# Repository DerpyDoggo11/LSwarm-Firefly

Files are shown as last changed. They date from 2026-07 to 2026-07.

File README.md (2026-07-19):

# LSwarm Firefly
A single motor Micro-Aerial Vehicle for drone swarm light displays

## Case
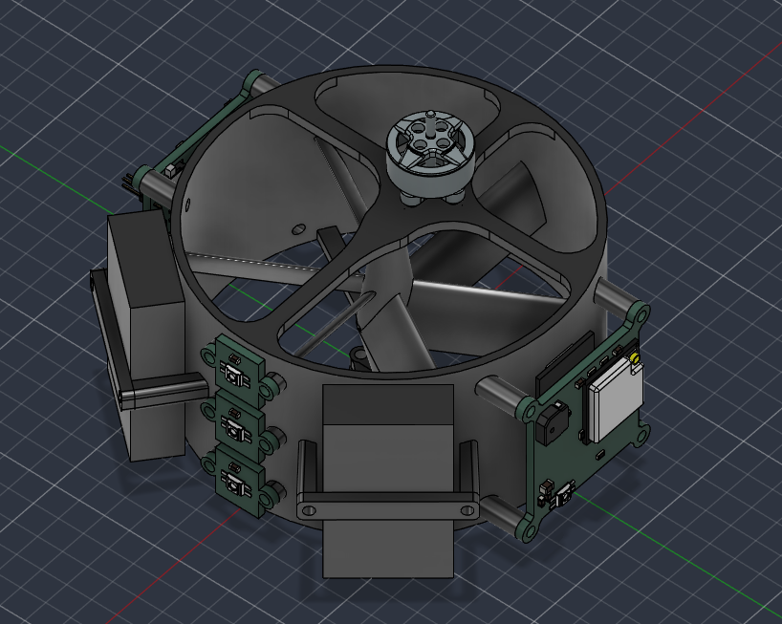
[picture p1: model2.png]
Case


## 3D PCB Preview
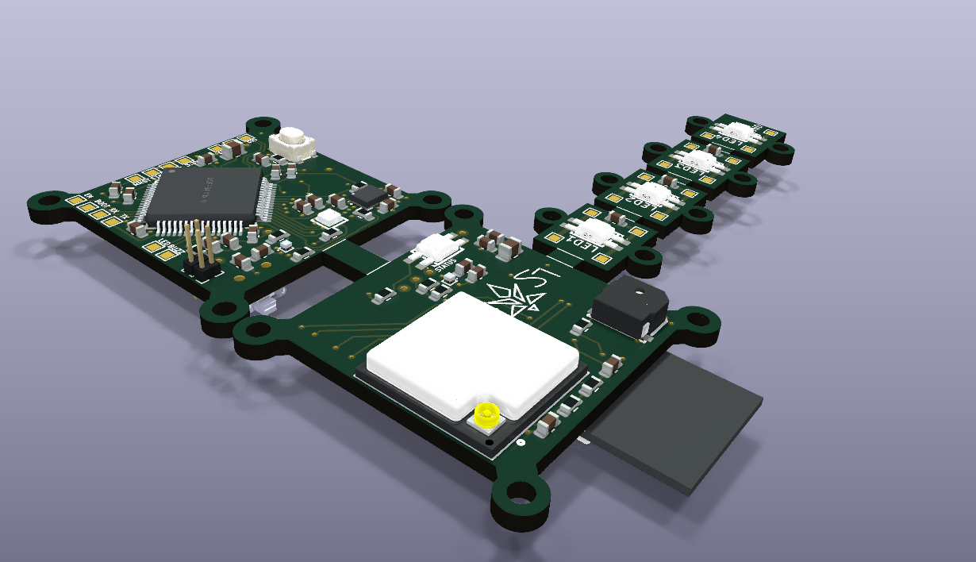
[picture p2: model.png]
3D PCB


## PCB Wiring
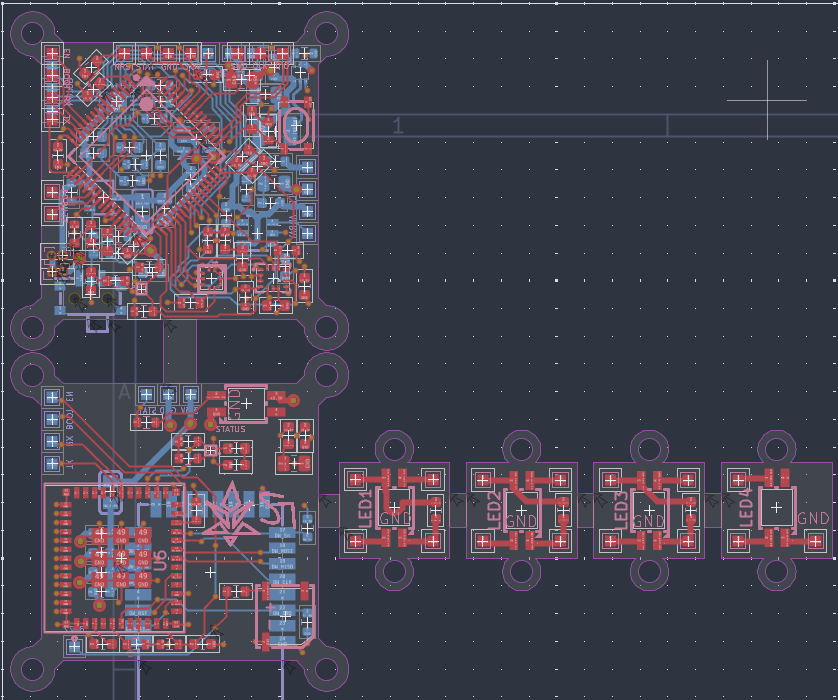
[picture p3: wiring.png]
PCB


## PCB Schematic
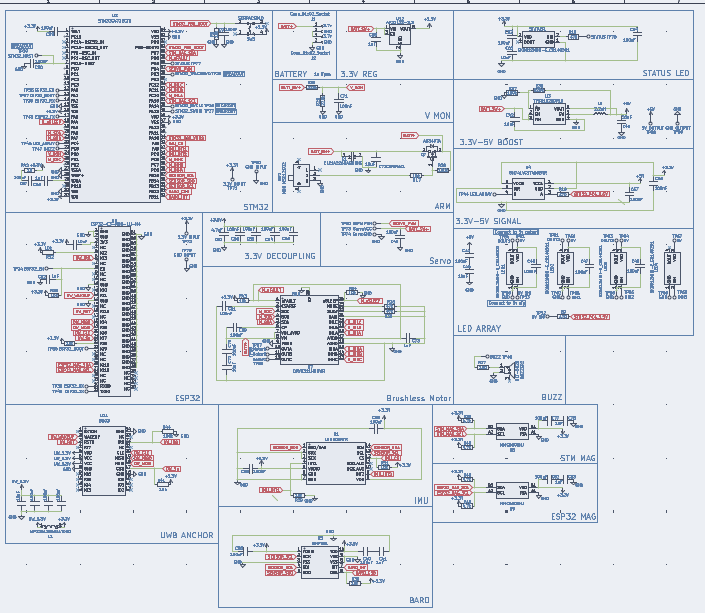
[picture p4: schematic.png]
Schematic


### Download ./latestProduction to fabricate your own PCB.

## Introduction
The LS Firefly is the baby brother to the original [LS Mk.1](https://github.com/DerpyDoggo11/LSwarm), the goal is to be smaller, safer, and a little more unique than the previous drone. Although it does come at some costs such as reduced manuverability and no USB-C connectivity. Like the previous model, rather than using GPS, it uses UWB frequencies to communicate with ground anchors (see [LS Anchor](https://github.com/DerpyDoggo11/LSwarm-Anchor)) for positioning. To fabricate these drones yourself, see the bill of materials below and follow the instructions. 

Note: this drone is all open sourced under the GNU GPL license! (do what you will with the code and designs but make sure to keep it open-source! :D)

### Are drone swarms legal in the US?
TLDR: yes and no, mostly no but sometimes yes. 

In the US, flying more than one drone by yourself outside is technically not legal without a permit, but flying indoors (or under some netting outside) is perfectly allowed, so make sure you understand this before buying or assembling any components.

If you live outside of the US, the restrictions will be different so make sure you check with your local government. 

## Bill of Materials 

### (Minimum build for testing: 5 drones)

| Quantity | Components | Price | Link |
|--- |---|---| -----|
| 5  | Brushless Motors | ~$56.27  | [here](https://www.aliexpress.us/item/3256811751884831.html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)
| 5 | 65mm Propellers (1.5mm hole) | $2.42 | [here](https://www.aliexpress.us/item/3256808528649872.html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) 
| 10  | 1s 300mAh Battery | ~$19.75 | [here](https://www.aliexpress.us/item/3256801127609470.html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) 
|5 | 2.4G Wifi Antennas | ~$3.52 | [here](https://www.aliexpress.us/item/3256802833801038.html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)
| 5  | LS Firefly PCBs | ~$25 (with shipping, cost can vary widely however) | Download repo, extract fabrication files, and fabricate pcb through JLCPCB, purchase components from LCSC (complete instructions for this may come soon)
| 5  | Electronics | ~$125 (with shipping, cost can vary widely however) | Purchase components from LCSC

Total cost: **$231,96**

Cost per drone: **$46.39**

## Tools / Other parts:
- Hot-air reflow station or SMD hot plate
- Soldering iron + solder
- Solder paste for SMD components
- Tweezers for SMD components

For drone light displays, you'll also need the [UWB anchors](https://github.com/DerpyDoggo11/LSwarm-Anchor) and a powerful MCU devboard or laptop.

## Assembly:
1. Apply solder paste to all smd components directly or through a stencil
2. Heat up components with a hot plate or hot-air gun
3. 3D print drone case
4. Mount components to drone case
4. Plug in USB-C port and upload software

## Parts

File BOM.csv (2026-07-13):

Quantity | Component | Price | Link
5 | Brushless Motor | $56.27 | https://www.aliexpress.us/item/3256811751884831.html?curPageLogUid=VGuc6eNMjhlE
5 | 1s 300mAh Battery | $19.75 | https://www.aliexpress.us/item/3256801127609470.html?curPageLogUid=hyAg3GWOKWbh
5 | 65mm Propellers (1.5mm hole) | $2.42 | https://www.aliexpress.us/item/3256808528649872.html?curPageLogUid=khfzd3PNDSbd
5 | 2.4G Wifi Antenna | $3.52 | https://www.aliexpress.us/item/3256802833801038.html?curPageLogUid=rLnZuf4b98Bi
5 | Custom PCB | $25 | Download repo, extract fabrication files, and fabricate pcb through JLCPCB
5 | Electronics | $125 | Purchase components from LCSC
Total: | $231.96
Cost Per Drone | $46.39

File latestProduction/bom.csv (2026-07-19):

Designator | Footprint | Quantity | Value | LCSC Part #
BUZZER2 | BUZ-SMD_L5.0-W5.5-P4.60 | 1 | MLT-5020 | C94598
C1 | C0805 | 1 | CL21A226MAQNNNE | C45783
C38, C39, C40, C44, C46, C47, C48, C50, C53, C54, C56, C57, C59, C60, C61, C62, C64, C66, C67, C68, C69, C70, C71, C77, C79, C80, C81, C82, C9 | 0603 | 29 | 100nF
C41, C52, C58, C65, C73, C78, C83 | 0603 | 7 | 1uF
C42, C45, C63, C71CERAMIC1 | 0805 | 4 | 10uF
C43 | 0805 | 1 | 22uF
C49 | 0603 | 1 | 100uF
C51 | 0603 | 1 | 4.7uF
C55, C72, C76 | 0603 | 3 | 10uF
J1, J2 | PinHeader_1x02_P1.00mm_Vertical | 2 | Conn_01x02_Socket
L1 | L0805 | 1 | MPZ2012S601AT000 | C21519
L5 | 1210 | 1 | 2.2uH
LED1, LED2, LED3, LED4, STATUS1 | LED-SMD_4P-L3.2-W2.8-LS5.9_SK6812MINI-E | 5 | SK6812MINI-E_C5149201 | C5149201
Q7 | SOT-23-3_L2.9-W1.6-P1.90-LS2.8-BR | 1 | AO3407A | C15155
R10, R19, R9 | 0603 | 3 | 470
R17, R18, R29, R30, R31, R32, R33, R34, R41, R43, R8 | 0603 | 11 | 10k
R25, R26 | 0603 | 2 | 220k
R27 | 0603 | 1 | 100
R28, R37, R44 | 0603 | 3 | 100k
R35, R39 | 0603 | 2 | 47k
R36 | 0603 | 1 | 820k
R38, R40, R45, R46 | 0603 | 4 | 4.7k
R42 | 0603 | 1 | 10
SW2 | SW-SMD_MSK12CO2 | 1 | MINI MSK12CO2 | C2681570
SW3 | KEY-SMD_4P-L4.2-W3.2-P2.20-LS4.6 | 1 | SKRPACE010 | C139797
TP26 | TestPoint_Pad_1.0x1.0mm | 1 | STM32_SWCLK
TP27 | TestPoint_Pad_1.0x1.0mm | 1 | STM32_SWDIO
TP28 | TestPoint_Pad_1.0x1.0mm | 1 | STM32_TRACESWO
TP29 | TestPoint_Pad_1.0x1.0mm | 1 | STM32_NRST
TP34, TP35 | TestPoint_Pad_1.0x1.0mm | 2 | ESP32_EN
TP36, TP37 | TestPoint_Pad_1.0x1.0mm | 2 | ESP32_BOOT
TP38, TP39 | TestPoint_Pad_1.0x1.0mm | 2 | ESP32_RX
TP40, TP43 | TestPoint_Pad_1.0x1.0mm | 2 | ESP32_TX
TP44, TP45 | TestPoint_Pad_1.0x1.0mm | 2 | LED_ARRAY
TP46, TP47 | TestPoint_Pad_1.0x1.0mm | 2 | BUZZ
TP50 | TestPoint_Pad_1.0x1.0mm | 1 | ServoPWM
TP51, TP60, TP64, TP67 | TestPoint_Pad_1.0x1.0mm | 4 | 5V
TP52, TP53 | TestPoint_Pad_1.0x1.0mm | 2 | 5V SIG
TP54 | TestPoint_Pad_1.0x1.0mm | 1 | DOUT1
TP55 | TestPoint_Pad_1.0x1.0mm | 1 | DIN1
TP56, TP62, TP66, TP69 | TestPoint_Pad_1.0x1.0mm | 4 | GND
TP58 | TestPoint_Pad_1.0x1.0mm | 1 | 5V OUTPUT
TP59 | TestPoint_Pad_1.0x1.0mm | 1 | GND OUTPUT
TP61 | TestPoint_Pad_1.0x1.0mm | 1 | DOUT2
TP63 | TestPoint_Pad_1.0x1.0mm | 1 | DOUT3
TP65 | TestPoint_Pad_1.0x1.0mm | 1 | DIN2
TP68 | TestPoint_Pad_1.0x1.0mm | 1 | DIN3
TP71, TP72 | TestPoint_Pad_1.0x1.0mm | 2 | 3.3V INPUT
TP73 | TestPoint_Pad_1.0x1.0mm | 1 | ServoVCC
TP74 | TestPoint_Pad_1.0x1.0mm | 1 | ServoGND
TP76, TP77 | TestPoint_Pad_1.0x1.0mm | 2 | STATUS
TP79, TP80 | TestPoint_Pad_1.0x1.0mm | 2 | GND INPUT
TP87 | TestPoint_Pad_1.0x1.0mm | 1 | MotorA
TP88 | TestPoint_Pad_1.0x1.0mm | 1 | MotorB
TP89 | TestPoint_Pad_1.0x1.0mm | 1 | MotorC
U1 | LGA-14_L3.0-W2.5-P0.50-BR | 1 | LSM6DSRTR | C784817
U11 | WIRELM-SMD_BU03 | 1 | BU03 | C42419011
U12 | SOT-23-5 | 1 | AP2112K-3.3
U2 | LQFP-64_L10.0-W10.0-P0.50-LS12.0-BL | 1 | STM32G473RCT6 | C529361
U3 | SOT-563_L1.6-W1.2-P0.50-LS1.6-BR | 1 | TPS61023DRLR | C919459
U4 | SOT-23-6_L2.9-W1.6-P0.95-LS2.8-BR | 1 | SN74LVC1T45DBVR | C7843
U5 | LGA-10_L2.0-W2.0-P0.50-TL_BMP581 | 1 | BMP581 | C5362283
U6 | WIFIM-SMD_61P-L13.2-W12.5-P0.80 | 1 | ESP32-C3-MINI-1U-N4 | C2911374
U7 | QFN-24_L3.0-W3.0-P0.40-TL-EP1.9_TI_RRW0024A | 1 | DRV8311HRRWR | C5218862
U8, U9 | FLIPCHIP-4_L0.8-W0.8-R2-C2-P0.40-TL | 2 | MMC5603NJ | C404328

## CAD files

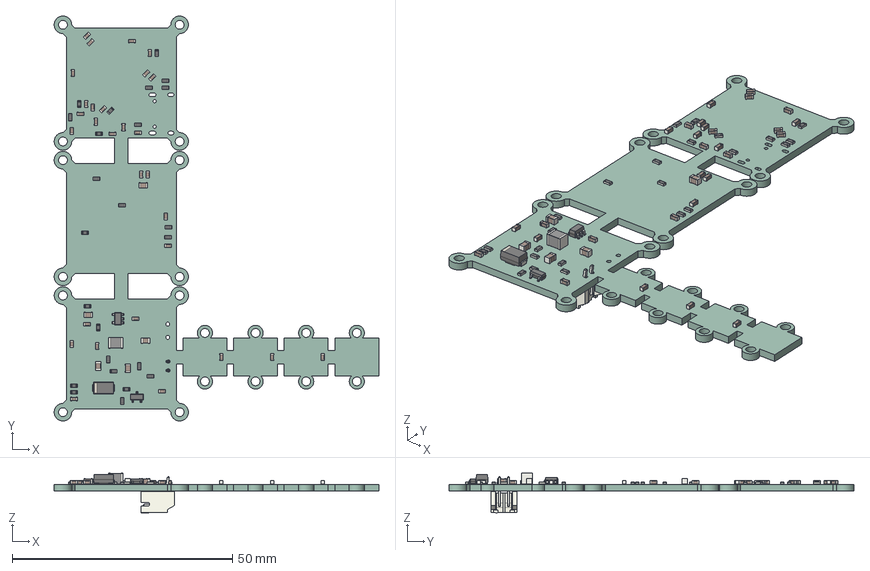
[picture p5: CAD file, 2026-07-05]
LSwarm Firefly/LSwarm Firefly.step
73.7 x 92.0 x 9.03 mm
SOT-23-5
C_0603_1608Metric x 29
R_0603_1608Metric x 24
D_SMA
C_0805_2012Metric x 5
L_1210_3225Metric
SOT-23
JST_PH_S2B-PH-K_1x02_P2.00mm_Horizontal
LSwarm Firefly_PCB

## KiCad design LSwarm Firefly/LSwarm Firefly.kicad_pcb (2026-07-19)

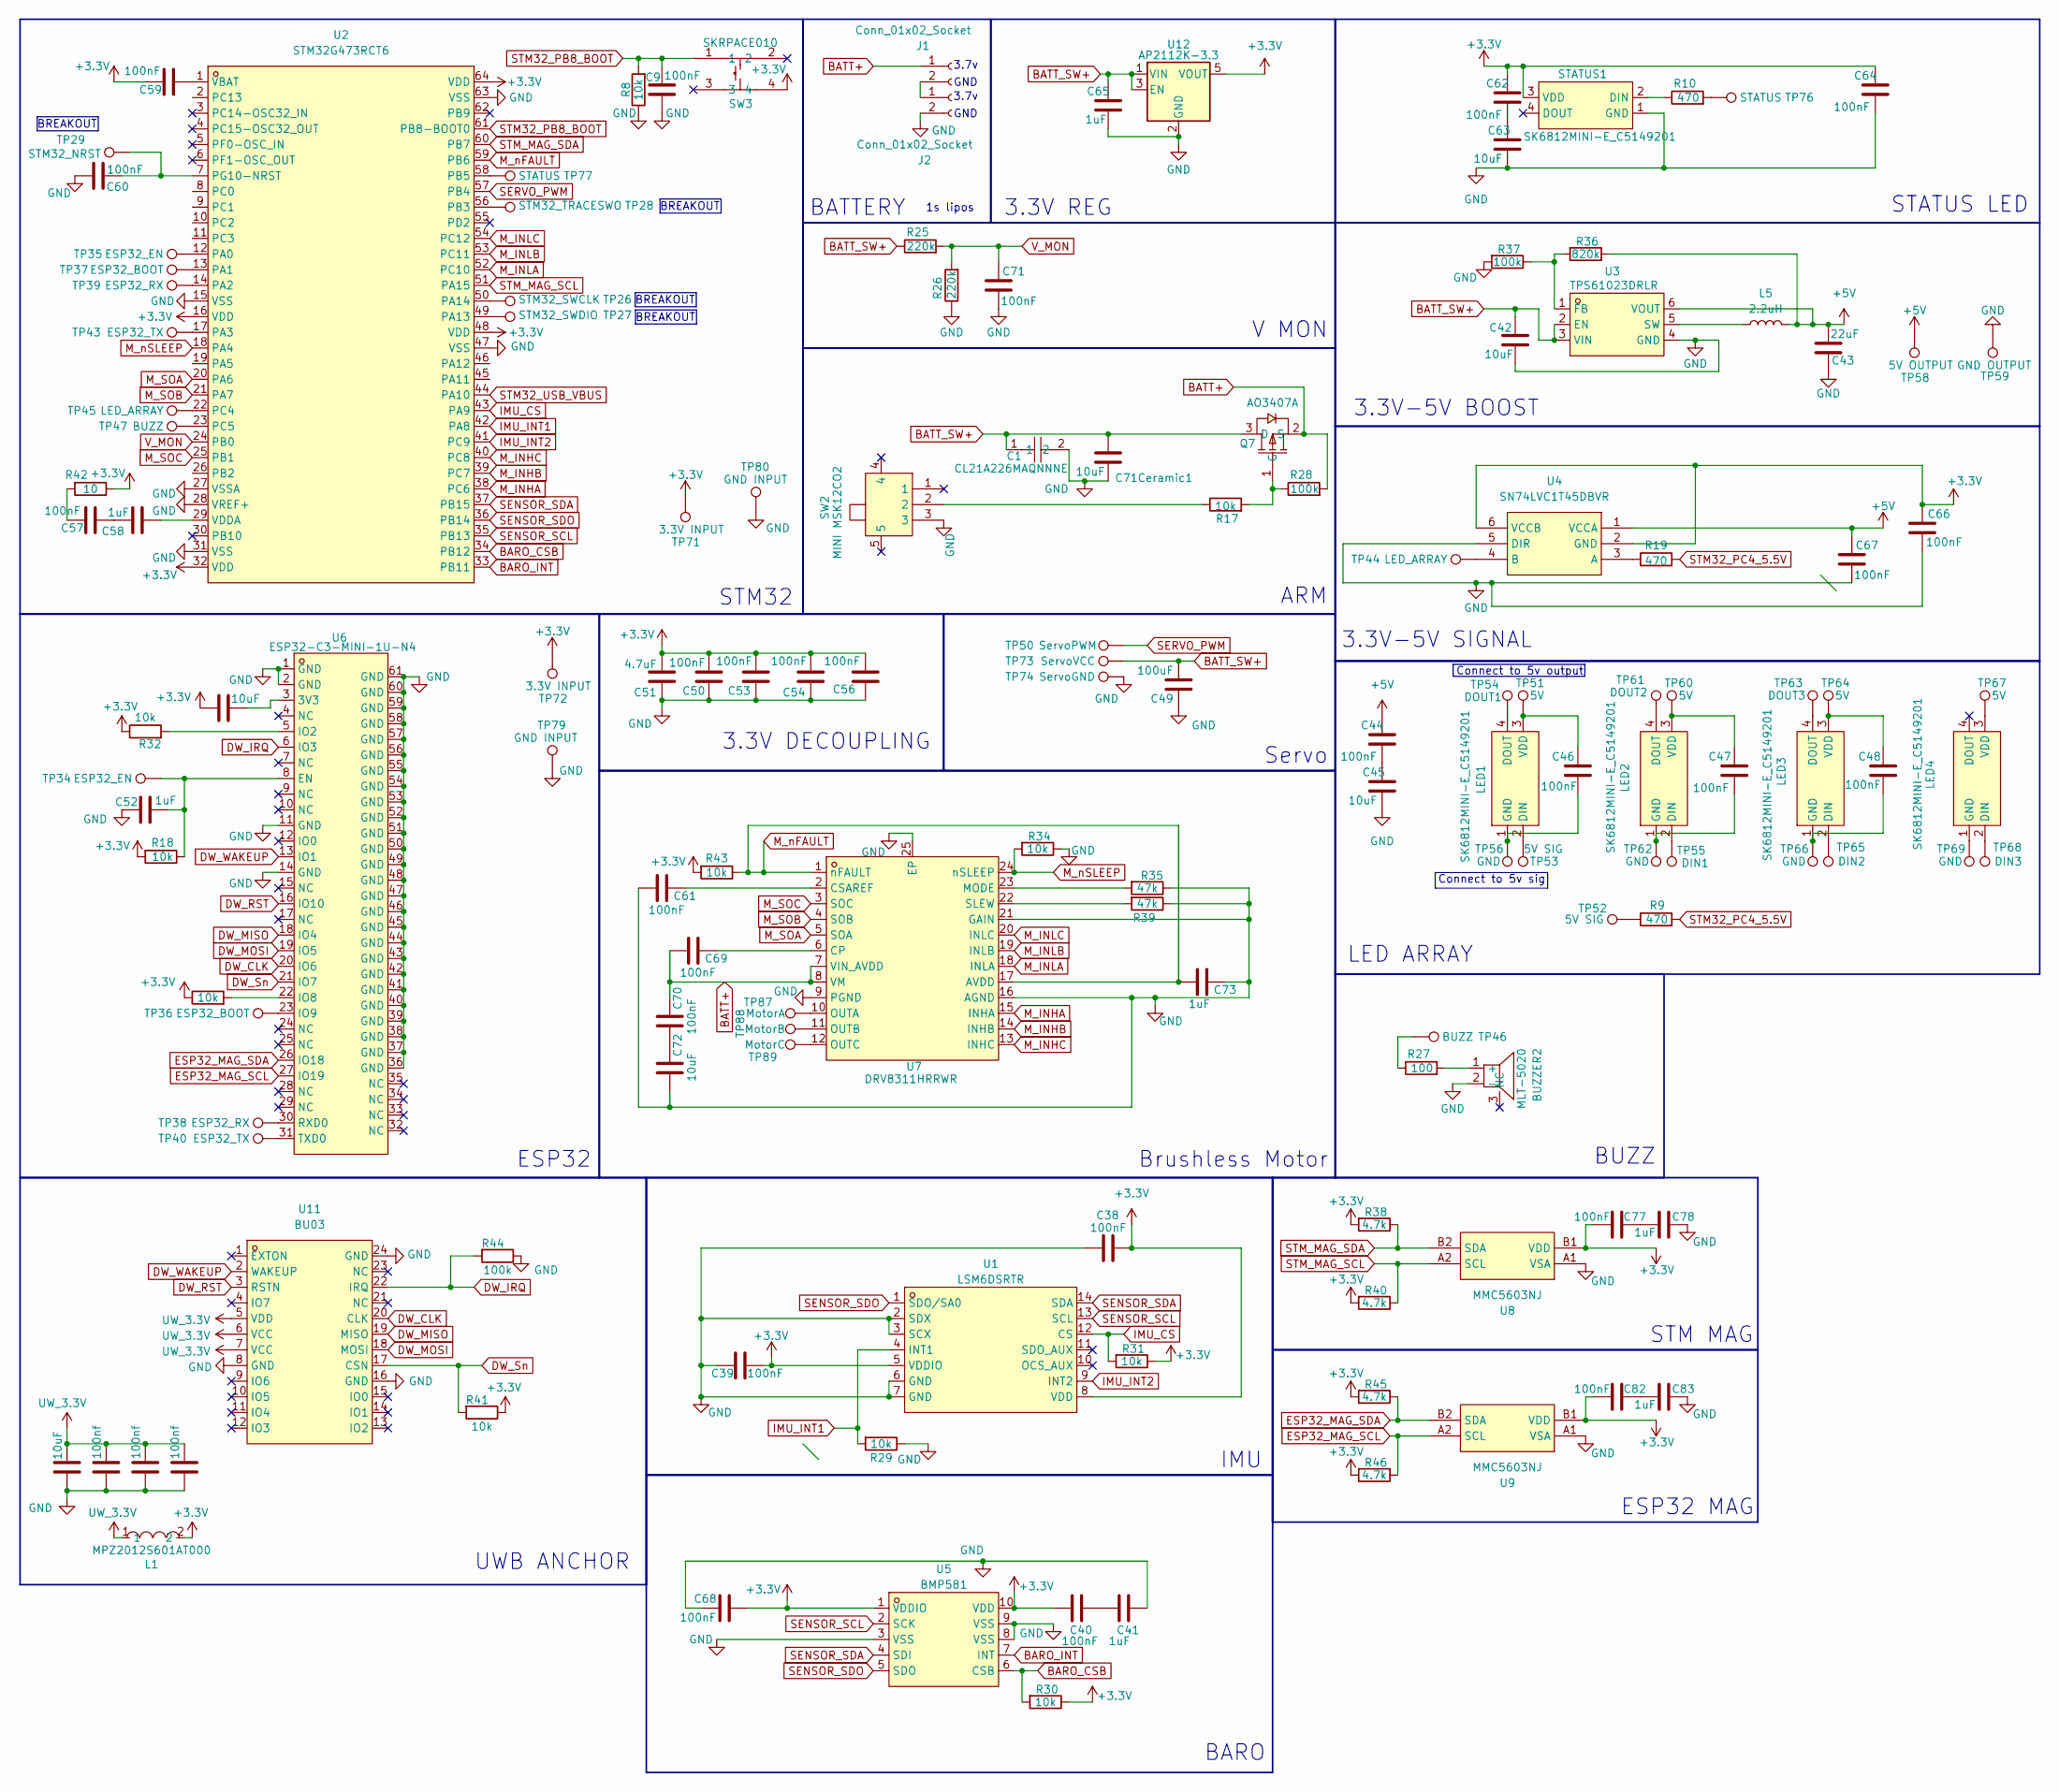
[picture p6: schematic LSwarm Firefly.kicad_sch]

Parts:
BUZZER2: MLT-5020; BUZ-SMD_L5.0-W5.5-P4.60; MPN MLT-5020; LCSC Part C94598
C1: CL21A226MAQNNNE; C0805; MPN CL21A226MAQNNNE; LCSC Part C45783
C9, C38, C39, C40, C44, C46, C47, C48, C50, C53, C54, C56, C57, C59, C60, C61, C62, C64, C66, C67, C68, C69, C70, C71, C77, C82: 100nF; C_0603_1608Metric
C41, C52, C58, C65, C73, C78, C83: 1uF; C_0603_1608Metric
C42, C45, C63, C71Ceramic1: 10uF; C_0805_2012Metric
C43: 22uF; C_0805_2012Metric
C49: 100uF; C_0603_1608Metric
C51: 4.7uF; C_0603_1608Metric
C55, C72, C76: 10uF; C_0603_1608Metric
C79, C80, C81: 100nf; C_0603_1608Metric
J1, J2: Conn_01x02_Socket; PinHeader_1x02_P1.00mm_Vertical
L1: MPZ2012S601AT000; L0805; MPN MPZ2012S601AT000; LCSC Part C21519
L5: 2.2uH; L_1210_3225Metric
LED1, LED2, LED3, LED4: SK6812MINI-E_C5149201; LED-SMD_4P-L3.2-W2.8-LS5.9_SK6812MINI-E; MPN SK6812MINI-E; LCSC Part C5149201
Q7: AO3407A; SOT-23-3_L2.9-W1.6-P1.90-LS2.8-BR; MPN AO3407A; LCSC Part C15155
R8, R17, R18, R29, R30, R31, R32, R33, R34, R41, R43: 10k; R_0603_1608Metric
R9, R10, R19: 470; R_0603_1608Metric
R25, R26: 220k; R_0603_1608Metric
R27: 100; R_0603_1608Metric
R28, R37, R44: 100k; R_0603_1608Metric
R35, R39: 47k; R_0603_1608Metric
R36: 820k; R_0603_1608Metric
R38, R40, R45, R46: 4.7k; R_0603_1608Metric
R42: 10; R_0603_1608Metric
STATUS1: SK6812MINI-E_C5149201; LED-SMD_4P-L3.2-W2.8-LS5.9_SK6812MINI-E; MPN SK6812MINI-E; LCSC Part C5149201
SW2: MINI MSK12CO2; SW-SMD_MSK12CO2; MPN MINI MSK12CO2; LCSC Part C2681570
SW3: SKRPACE010; KEY-SMD_4P-L4.2-W3.2-P2.20-LS4.6; MPN SKRPACE010; LCSC Part C139797
TP26: STM32_SWCLK; TestPoint_Pad_1.0x1.0mm
TP27: STM32_SWDIO; TestPoint_Pad_1.0x1.0mm
TP28: STM32_TRACESWO; TestPoint_Pad_1.0x1.0mm
TP29: STM32_NRST; TestPoint_Pad_1.0x1.0mm
TP34, TP35: ESP32_EN; TestPoint_Pad_1.0x1.0mm
TP36, TP37: ESP32_BOOT; TestPoint_Pad_1.0x1.0mm
TP38, TP39: ESP32_RX; TestPoint_Pad_1.0x1.0mm
TP40, TP43: ESP32_TX; TestPoint_Pad_1.0x1.0mm
TP44, TP45: LED_ARRAY; TestPoint_Pad_1.0x1.0mm
TP46, TP47: BUZZ; TestPoint_Pad_1.0x1.0mm
TP50: ServoPWM; TestPoint_Pad_1.0x1.0mm
TP51, TP60, TP64, TP67: 5V; TestPoint_Pad_1.0x1.0mm
TP52, TP53: 5V SIG; TestPoint_Pad_1.0x1.0mm
TP54: DOUT1; TestPoint_Pad_1.0x1.0mm
TP55: DIN1; TestPoint_Pad_1.0x1.0mm
TP56, TP62, TP66, TP69: GND; TestPoint_Pad_1.0x1.0mm
TP58: 5V OUTPUT; TestPoint_Pad_1.0x1.0mm
TP59: GND OUTPUT; TestPoint_Pad_1.0x1.0mm
TP61: DOUT2; TestPoint_Pad_1.0x1.0mm
TP63: DOUT3; TestPoint_Pad_1.0x1.0mm
TP65: DIN2; TestPoint_Pad_1.0x1.0mm
TP68: DIN3; TestPoint_Pad_1.0x1.0mm
TP71, TP72: 3.3V INPUT; TestPoint_Pad_1.0x1.0mm
TP73: ServoVCC; TestPoint_Pad_1.0x1.0mm
TP74: ServoGND; TestPoint_Pad_1.0x1.0mm
TP76, TP77: STATUS; TestPoint_Pad_1.0x1.0mm
TP79, TP80: GND INPUT; TestPoint_Pad_1.0x1.0mm
TP87: MotorA; TestPoint_Pad_1.0x1.0mm
TP88: MotorB; TestPoint_Pad_1.0x1.0mm
TP89: MotorC; TestPoint_Pad_1.0x1.0mm
U1: LSM6DSRTR; LGA-14_L3.0-W2.5-P0.50-BR; MPN LSM6DSRTR; LCSC Part C784817
U2: STM32G473RCT6; LQFP-64_L10.0-W10.0-P0.50-LS12.0-BL; MPN STM32G473RCT6; LCSC Part C529361
U3: TPS61023DRLR; SOT-563_L1.6-W1.2-P0.50-LS1.6-BR; MPN TPS61023DRLR; LCSC Part C919459
U4: SN74LVC1T45DBVR; SOT-23-6_L2.9-W1.6-P0.95-LS2.8-BR; MPN SN74LVC1T45DBVR; LCSC Part C7843
U5: BMP581; LGA-10_L2.0-W2.0-P0.50-TL_BMP581; MPN BMP581; LCSC Part C5362283
U6: ESP32-C3-MINI-1U-N4; WIFIM-SMD_61P-L13.2-W12.5-P0.80; MPN ESP32-C3-MINI-1U-N4; LCSC Part C2911374
U7: DRV8311HRRWR; QFN-24_L3.0-W3.0-P0.40-TL-EP1.9_TI_RRW0024A; MPN DRV8311HRRWR; LCSC Part C5218862
U8, U9: MMC5603NJ; FLIPCHIP-4_L0.8-W0.8-R2-C2-P0.40-TL; MPN MMC5603NJ; LCSC Part C404328
U11: BU03; WIRELM-SMD_BU03; MPN BU03; LCSC Part C42419011
U12: AP2112K-3.3; SOT-23-5

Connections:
+3.3V: C38.1, C39.1, C40.2, C50.2, C51.2, C53.2, C54.2, C55.2, C56.2, C59.1, C62.2, C64.2, C66.2, C68.1, C77.1, C82.1, L1.2, R18.2, R30.1, R31.1, R32.1, R33.1, R38.2, R40.2, R41.1, R42.1, R43.2, R45.2, R46.2, STATUS1.3 (VDD), SW3.4, TP71.1 (1_1), TP72.1 (1_1), U1.5 (VDDIO), U1.8 (VDD), U2.16 (VDD), U2.32 (VDD), U2.48 (VDD), U2.64 (VDD), U4.2 (GND), U4.6 (VCCB), U5.1 (VDDIO), U5.10 (VDD), U8.B1 (VDD), U9.B1 (VDD), U12.5 (VOUT)
+5V: C43.2, C44.2, C67.2, L5.2, R36.1, TP58.1 (1_1), U3.6 (VOUT), U4.1 (VCCA)
BARO_CSB: R30.2, U2.34 (PB12), U5.6 (CSB)
BARO_INT: U2.33 (PB11), U5.7 (INT)
BATT+: C69.2, C70.1, J1.1, Q7.2 (S), R28.2, U7.7 (VIN_AVDD), U7.8 (VM)
BATT_SW+: C1.1, C42.1, C49.2, C65.2, C71Ceramic1.2, Q7.3 (D), R25.1, TP73.1 (1_1), U3.2 (EN), U3.3 (VIN), U12.1 (VIN), U12.3 (EN)
DW_CLK: U6.20 (IO6), U11.20 (CLK)
DW_IRQ: R44.2, U6.6 (IO3), U11.22 (IRQ)
DW_MISO: U6.18 (IO4), U11.19 (MISO)
DW_MOSI: U6.19 (IO5), U11.18 (MOSI)
DW_RST: U6.16 (IO10), U11.3 (RSTN)
DW_Sn: R41.2, U6.21 (IO7), U11.17 (CSN)
DW_WAKEUP: U6.13 (IO1), U11.2 (WAKEUP)
ESP32_MAG_SCL: R46.1, U6.27 (IO19), U9.A2 (SCL)
ESP32_MAG_SDA: R45.1, U6.26 (IO18), U9.B2 (SDA)
GND: BUZZER2.2 (-), C1.2, C9.2, C38.2, C39.2, C41.1, C42.2, C43.1, C45.1, C49.1, C50.1, C51.1, C52.1, C53.1, C54.1, C56.1, C60.1, C61.2, C63.1, C64.1, C65.1, C66.1, C67.1, C68.2, C71.1, C71Ceramic1.1, C72.2, C73.1, C76.2, C78.2, C79.2, C80.2, C81.2, C83.2, J2.2, R8.1, R26.1, R29.1, R34.1, R35.1, R37.2, R39.1, R44.1, STATUS1.1 (GND), SW2.3, TP59.1 (1_1), TP74.1 (1_1), TP79.1 (1_1), TP80.1 (1_1), U1.2 (SDX), U1.3 (SCX), U1.6 (GND), U1.7 (GND), U2.15 (VSS), U2.27 (VSSA), U2.28 (VREF+), U2.31 (VSS), U2.47 (VSS), U2.63 (VSS), U3.4 (GND), U4.5 (DIR), U5.3 (VSS), U5.8 (VSS), U5.9 (VSS), U6.1 (GND), U6.2 (GND), U6.11 (GND), U6.14 (GND), U6.36 (GND), U6.37 (GND), U6.38 (GND), U6.39 (GND), U6.40 (GND), U6.41 (GND), U6.42 (GND), U6.43 (GND), U6.44 (GND), U6.45 (GND), U6.46 (GND), U6.47 (GND), U6.48 (GND), U6.49 (GND), U6.50 (GND), U6.51 (GND), U6.52 (GND), U6.53 (GND), U6.54 (GND), U6.55 (GND), U6.56 (GND), U6.57 (GND), U6.58 (GND), U6.59 (GND), U6.60 (GND), U6.61 (GND), U7.9 (PGND), U7.16 (AGND), U7.21 (GAIN), U7.25 (EP), U8.A1 (VSA), U9.A1 (VSA), U11.8 (GND), U11.16 (GND), U11.24 (GND), U12.2 (GND)
IMU_CS: R31.2, U1.12 (CS), U2.43 (PA9)
IMU_INT1: R29.2, U1.4 (INT1), U2.42 (PA8)
IMU_INT2: U1.9 (INT2), U2.41 (PC9)
M_INHA: U2.38 (PC6), U7.15 (INHA)
M_INHB: U2.39 (PC7), U7.14 (INHB)
M_INHC: U2.40 (PC8), U7.13 (INHC)
M_INLA: U2.52 (PC10), U7.18 (INLA)
M_INLB: U2.53 (PC11), U7.19 (INLB)
M_INLC: U2.54 (PC12), U7.20 (INLC)
M_SOA: U2.20 (PA6), U7.5 (SOA)
M_SOB: U2.21 (PA7), U7.4 (SOB)
M_SOC: U2.25 (PB1), U7.3 (SOC)
M_nFAULT: C73.2, R43.1, U2.59 (PB6), U7.1 (nFAULT), U7.17 (AVDD)
M_nSLEEP: R34.2, U2.18 (PA4), U7.24 (nSLEEP)
unnamed: BUZZER2.1 (+), R27.2
unnamed: C40.1, C41.2
unnamed: C44.1, C45.2
unnamed: C57.1, R42.2
unnamed: C57.2, C58.1
unnamed: C62.1, C63.2
unnamed: C70.2, C72.1
unnamed: C77.2, C78.1
unnamed: C82.2, C83.1
unnamed: J1.2, J2.1
unnamed: LED1.2 (DIN), TP53.1 (1_1)
unnamed: LED1.4 (DOUT), TP54.1 (1_1)
unnamed: C46.1, LED1.1 (GND), TP56.1 (1_1)
unnamed: C46.2, LED1.3 (VDD), TP51.1 (1_1)
unnamed: LED2.2 (DIN), TP55.1 (1_1)
unnamed: LED2.4 (DOUT), TP61.1 (1_1)
unnamed: C47.1, LED2.1 (GND), TP62.1 (1_1)
unnamed: C47.2, LED2.3 (VDD), TP60.1 (1_1)
unnamed: LED3.2 (DIN), TP65.1 (1_1)
unnamed: LED3.4 (DOUT), TP63.1 (1_1)
unnamed: C48.1, LED3.1 (GND), TP66.1 (1_1)
unnamed: C48.2, LED3.3 (VDD), TP64.1 (1_1)
unnamed: LED4.2 (DIN), TP68.1 (1_1)
unnamed: LED4.1 (GND), TP69.1 (1_1)
unnamed: LED4.3 (VDD), TP67.1 (1_1)
unnamed: Q7.1 (G), R17.2, R28.1
unnamed: R9.1, TP52.1 (1_1)
unnamed: R10.2, TP76.1 (1_1)
unnamed: R17.1, SW2.2
unnamed: R27.1, TP46.1 (1_1)
unnamed: R10.1, STATUS1.2 (DIN)
unnamed: TP35.1 (1_1), U2.12 (PA0)
unnamed: TP37.1 (1_1), U2.13 (PA1)
unnamed: TP39.1 (1_1), U2.14 (PA2)
unnamed: TP43.1 (1_1), U2.17 (PA3)
unnamed: TP27.1 (1_1), U2.49 (PA13)
unnamed: TP26.1 (1_1), U2.50 (PA14)
unnamed: TP28.1 (1_1), U2.56 (PB3)
unnamed: TP77.1 (1_1), U2.58 (PB5)
unnamed: TP45.1 (1_1), U2.22 (PC4)
unnamed: TP47.1 (1_1), U2.23 (PC5)
unnamed: C60.2, TP29.1 (1_1), U2.7 (PG10-NRST)
unnamed: C59.2, U2.1 (VBAT)
unnamed: C58.2, U2.29 (VDDA)
unnamed: R36.2, R37.1, U3.1 (FB)
unnamed: L5.1, U3.5 (SW)
unnamed: R19.2, U4.3 (A)
unnamed: TP44.1 (1_1), U4.4 (B)
unnamed: C55.1, U6.3 (3V3)
unnamed: C52.2, R18.1, TP34.1 (1_1), U6.8 (EN)
unnamed: R32.2, U6.5 (IO2)
unnamed: R33.2, U6.22 (IO8)
unnamed: TP36.1 (1_1), U6.23 (IO9)
unnamed: TP38.1 (1_1), U6.30 (RXD0)
unnamed: TP40.1 (1_1), U6.31 (TXD0)
unnamed: C69.1, U7.6 (CP)
unnamed: C61.1, U7.2 (CSAREF)
unnamed: R35.2, U7.23 (MODE)
unnamed: TP87.1 (1_1), U7.10 (OUTA)
unnamed: TP88.1 (1_1), U7.11 (OUTB)
unnamed: TP89.1 (1_1), U7.12 (OUTC)
unnamed: R39.2, U7.22 (SLEW)
SENSOR_SCL: U1.13 (SCL), U2.35 (PB13), U5.2 (SCK)
SENSOR_SDA: U1.14 (SDA), U2.37 (PB15), U5.4 (SDI)
SENSOR_SDO: U1.1 (SDO/SA0), U2.36 (PB14), U5.5 (SDO)
SERVO_PWM: TP50.1 (1_1), U2.57 (PB4)
STM32_PB8_BOOT: C9.1, R8.2, SW3.1, U2.61 (PB8-BOOT0)
STM32_PC4_5.5V: R9.2, R19.1
STM32_USB_VBUS: U2.44 (PA10)
STM_MAG_SCL: R40.1, U2.51 (PA15), U8.A2 (SCL)
STM_MAG_SDA: R38.1, U2.60 (PB7), U8.B2 (SDA)
UW_3.3V: C76.1, C79.1, C80.1, C81.1, L1.1, U11.5 (VDD), U11.6 (VCC), U11.7 (VCC)
V_MON: C71.2, R25.2, R26.2, U2.24 (PB0)

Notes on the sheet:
3.3V DECOUPLING
3.3V REG
BUZZ
BREAKOUT
GND
Connect to 5v output
Connect to 5v sig
STM32
STM MAG
3.7v
ESP32 MAG
BARO
1s lipos
ARM
Brushless Motor
3.3V-5V SIGNAL
3.3V-5V BOOST
LED ARRAY
Servo
V MON
STATUS LED
ESP32
UWB ANCHOR
BATTERY
IMU

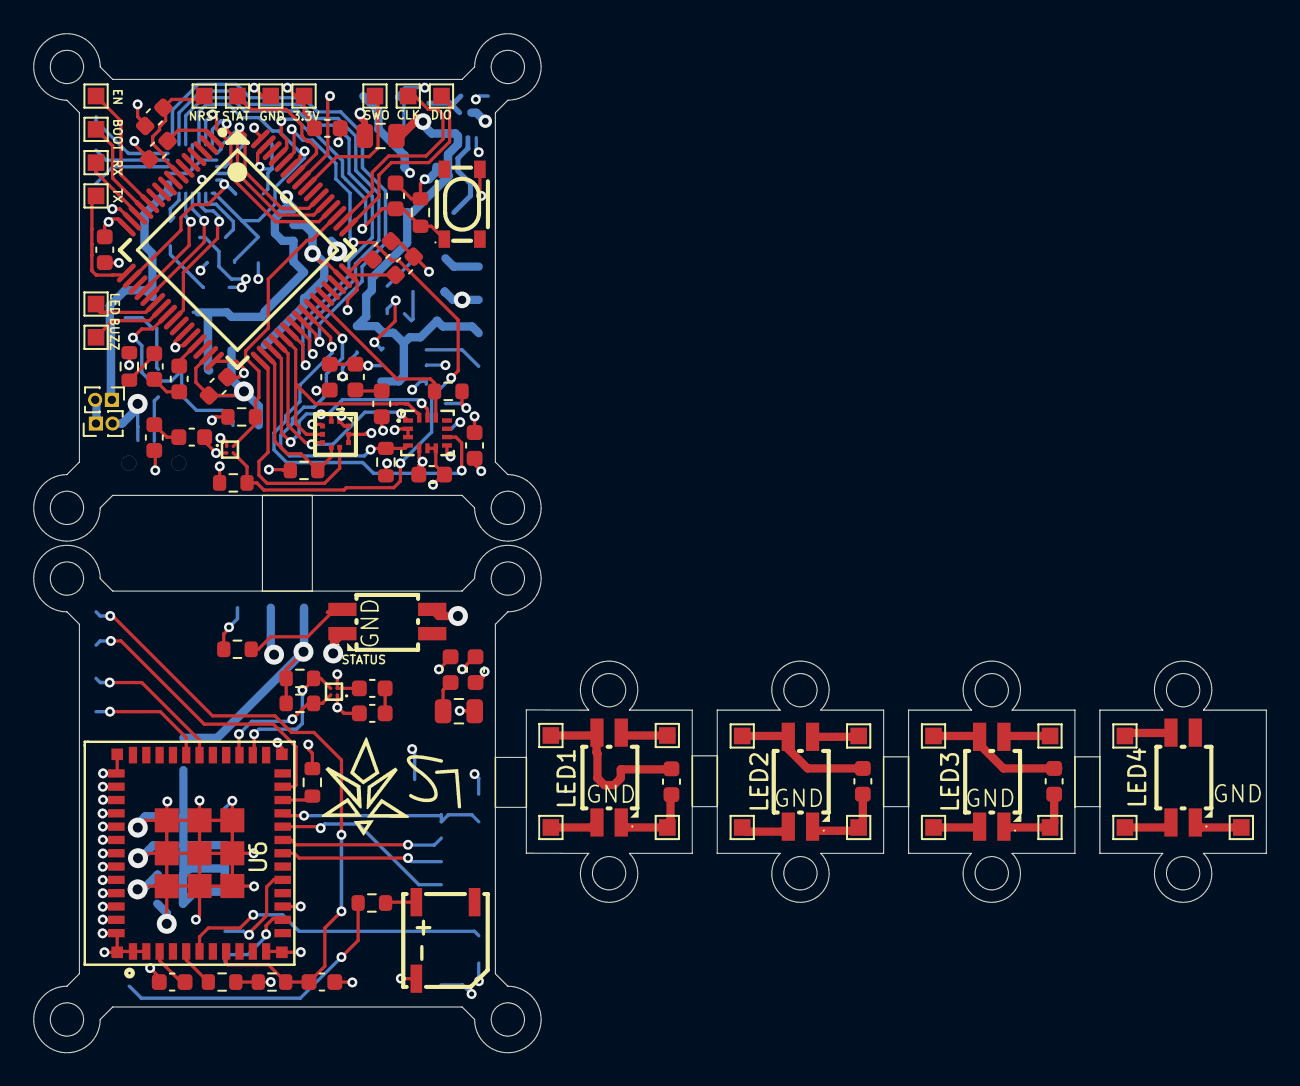
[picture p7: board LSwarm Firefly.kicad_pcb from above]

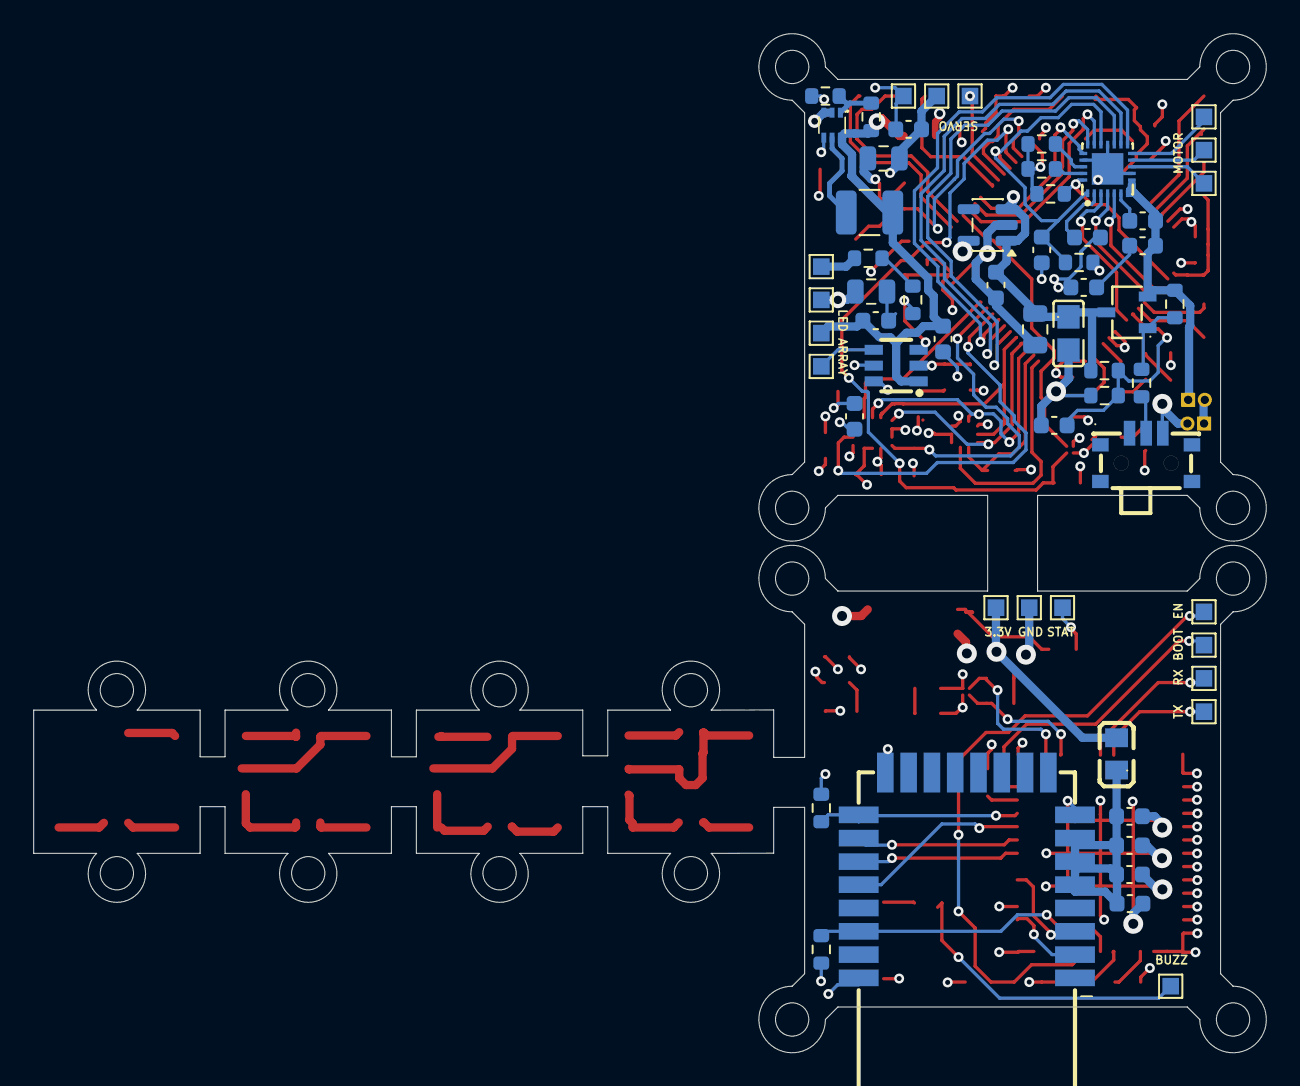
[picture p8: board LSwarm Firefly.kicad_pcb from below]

Board: 4 copper layers, 74.1 x 61.2 mm, 145 parts (60 on the bottom side), 102 nets.

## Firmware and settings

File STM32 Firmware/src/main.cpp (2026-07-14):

#include <Arduino.h>
#include "pins.h"
#include "sensors.h"
#include "motor.h"
#include "leds.h"
#include "io.h"
#include "esp_link.h"

static bool  g_armed = false;
static float g_vbat  = 0.0f;
static bool  g_sensorsOk = false;

static bool  g_spinning  = false;
static float g_spinHz    = 0.0f;
static float g_spinAmp   = 0.0f;

static void safeShutdown(const char* why) {
    g_armed    = false;
    g_spinning = false;
    Motor::disable();
    Leds::statusError();
    Buzzer::beep(400);
    Serial.printf("!! DISARMED: %s\n", why);
}

static void handleCommand(char* cmd) {
    if (!strcmp(cmd, "help")) {
        Serial.println("arm | disarm | spin <elec_hz> <amp 0-1> | stop |");
        Serial.println("duty <a> <b> <c> | servo <us> | stat | imu | mag |");
        Serial.println("baro | fault | esp_reset | esp_boot | esp_bridge");
    }
    else if (!strcmp(cmd, "arm")) {
        if (!g_sensorsOk)                 { Serial.println("refused: sensors failed"); return; }
        if (Motor::faulted())             { Serial.println("refused: DRV8311 fault"); return; }
        if (g_vbat < VBAT_CRITICAL && !Power::usbPresent()) {
            Serial.println("refused: battery low"); return;
        }
        Motor::enable();
        g_armed = true;
        Leds::statusArmed();
        Buzzer::beep(120);
        Serial.println("ARMED");
    }
    else if (!strcmp(cmd, "disarm") || !strcmp(cmd, "stop")) {
        g_armed = g_spinning = false;
        Motor::disable();
        Leds::statusIdle();
        Serial.println("disarmed");
    }
    else if (!strncmp(cmd, "spin ", 5)) {
        float hz, amp;
        if (sscanf(cmd + 5, "%f %f", &hz, &amp) == 2) {
            if (!g_armed) { Serial.println("arm first"); return; }
            g_spinHz   = hz;
            g_spinAmp  = constrain(amp, 0.0f, 0.6f);
            g_spinning = true;
            Serial.printf("open-loop spin: %.1f Hz elec, amp %.2f\n", g_spinHz, g_spinAmp);
        }
    }
    else if (!strncmp(cmd, "duty ", 5)) {
        float a, b, c;
        if (sscanf(cmd + 5, "%f %f %f", &a, &b, &c) == 3) {
            g_spinning = false;
            Motor::setPhaseDuty(a, b, c);
            Serial.printf("duty %.2f %.2f %.2f\n", a, b, c);
        }
    }
    else if (!strncmp(cmd, "servo ", 6)) {
        int us = atoi(cmd + 6);
        ServoOut::setMicros((uint16_t)us);
        Serial.printf("servo %d us\n", us);
    }
    else if (!strcmp(cmd, "stat")) {
        Serial.printf("vbat %.2f V  usb %d  armed %d  fault %d\n", g_vbat, (int)Power::usbPresent(), (int)g_armed, (int)Motor::faulted());
        Serial.printf("imu %d  baro %d  mag %d\n", (int)Sensors::imuOk(), (int)Sensors::baroOk(), (int)Sensors::magOk());
        Motor::Currents c = Motor::readCurrents();
        Serial.printf("isense %.3f %.3f %.3f V\n", c.a, c.b, c.c);
    }
    else if (!strcmp(cmd, "imu")) {
        ImuSample s;
        if (Sensors::readImu(s))
            Serial.printf("acc %.2f %.2f %.2f g | gyro %.1f %.1f %.1f dps\n", s.ax, s.ay, s.az, s.gx, s.gy, s.gz);
        else Serial.println("imu not present");
    }
    else if (!strcmp(cmd, "baro")) {
        BaroSample s;
        if (Sensors::readBaro(s))
            Serial.printf("%.1f Pa  %.1f C  alt %.1f m\n", s.pressure_pa, s.temperature_c, s.altitude_m);
        else Serial.println("baro not present");
    }
    else if (!strcmp(cmd, "mag")) {
        MagSample s;
        if (Sensors::readMag(s))
            Serial.printf("mag %.3f %.3f %.3f G\n", s.mx, s.my, s.mz);
        else Serial.println("mag not present");
    }
    else if (!strcmp(cmd, "fault")) {
        Serial.printf("nFAULT %s\n", Motor::faulted() ? "ASSERTED" : "clear");
        Motor::clearFault();
        Serial.println("fault latch cleared");
    }
    else if (!strcmp(cmd, "esp_reset")) { EspLink::reset(); Serial.println("esp reset"); }
    else if (!strcmp(cmd, "esp_boot"))  { EspLink::enterBootloader(); Serial.println("esp in bootloader"); }
    else if (!strcmp(cmd, "esp_bridge")) {
        Serial.println("bridge mode: ESP is in the ROM bootloader.");
        Serial.println("flash with --before no_reset --after no_reset");
        Serial.flush();
        EspLink::passthrough(); 
    }
    else if (cmd[0]) {
        Serial.println("? try 'help'");
    }
}

void setup() {
    Serial.begin(115200);

    Leds::begin();
    Leds::statusWarn();
    Buzzer::begin();
    Power::begin();
    ServoOut::begin();

    Motor::begin(); 
    EspLink::begin();

    g_sensorsOk = Sensors::begin();

    uint32_t t0 = millis();
    while (!Serial && millis() - t0 < 2000) { }

    Serial.println("\n=== STM32G473 flight controller ===");
    Serial.printf("IMU  (LSM6DSR) : %s\n", Sensors::imuOk()  ? "ok" : "FAIL");
    Serial.printf("BARO (BMP581)  : %s\n", Sensors::baroOk() ? "ok" : "FAIL");
    Serial.printf("MAG  (MMC5603) : %s\n", Sensors::magOk()  ? "ok" : "FAIL");
    Serial.printf("DRV8311 fault  : %s\n", Motor::faulted() ? "ASSERTED" : "clear");
    Serial.printf("VBAT           : %.2f V\n", Power::batteryVolts());
    Serial.println("type 'help'; 'esp_bridge' to flash the ESP32-C3");

    Leds::statusIdle();
    Buzzer::beep(60);
}

void loop() {
    static char    line[64];
    static uint8_t n = 0;
    while (Serial.available()) {
        char c = (char)Serial.read();
        if (c == '\n' || c == '\r') {
            if (n) { line[n] = '\0'; handleCommand(line); n = 0; }
        } else if (n < sizeof(line) - 1) {
            line[n++] = c;
        }
    }

    while (EspSerial.available()) Serial.write((char)EspSerial.read());

    static uint32_t nextCtl = 0;
    uint32_t now = micros();
    if ((int32_t)(now - nextCtl) >= 0) {
        nextCtl = now + 200;

        if (Motor::enabled() && Motor::faulted()) {
            safeShutdown("DRV8311 nFAULT");
        }
        else if (g_armed && g_spinning) {
            Motor::openLoopSpin(g_spinHz, g_spinAmp, 0.0002f);
        }
    }

    static uint32_t tHk = 0;
    if (millis() - tHk >= 200) {
        tHk = millis();
        g_vbat = Power::batteryVolts();

        if (!g_sensorsOk)                             Leds::statusError();
        else if (g_vbat < VBAT_CRITICAL)              Leds::statusError();
        else if (g_vbat < VBAT_WARN)                  Leds::statusWarn();
        else if (g_armed)                             Leds::statusArmed();
        else                                          Leds::statusIdle();

        if (g_armed && g_vbat < VBAT_CRITICAL && !Power::usbPresent()) {
            safeShutdown("low voltage");
        }
    }
}

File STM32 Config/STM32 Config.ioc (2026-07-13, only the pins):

Mcu.UserName=STM32G473RCTx
PA0.Signal=GPIO_Output
PA1.Signal=GPIO_Output
PA10.Signal=GPIO_Input
PA11.Signal=USB_DM
PA12.Signal=USB_DP
PA13.Signal=SYS_JTMS-SWDIO
PA14.Signal=SYS_JTCK-SWCLK
PA15.Signal=I2C1_SCL
PA2.Signal=USART2_TX
PA3.Signal=USART2_RX
PA5.Signal=ADC2_IN13
PA6.Signal=ADC2_IN3
PA8.Signal=GPIO_Output
PA9.Signal=GPIO_Input
PB0.Signal=ADC1_IN15
PB1.Signal=ADC3_IN1
PB11.Signal=GPIO_Output
PB12.Signal=GPIO_Input
PB13.Signal=SPI2_SCK
PB14.Signal=SPI2_MISO
PB15.Signal=SPI2_MOSI
PB2.Signal=I2C3_SMBA
PB3.Signal=SYS_JTDO-SWO
PB4.Signal=GPXTI4
PB5.Signal=GPIO_Output
PB6.Signal=TIM8_BKIN2
PB7.Signal=I2C1_SDA
PB8-BOOT0.Signal=GPIO_Input
PC10.Signal=TIM8_CH1N
PC11.Signal=TIM8_CH2N
PC12.Signal=TIM8_CH3N
PC2.Signal=GPIO_Output
PC3.Signal=GPIO_Output
PC4.Signal=GPIO_Output
PC5.Signal=GPIO_Output
PC6.Signal=S_TIM8_CH1
PC7.Signal=S_TIM8_CH2
PC8.Signal=S_TIM8_CH3
PC9.Signal=GPIO_Output
PG10-NRST.Signal=GPIO_Output

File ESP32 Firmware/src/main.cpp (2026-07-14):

#include <SPI.h>
#include <Wire.h>
#include "pins.h"

static SPIClass dwSpi(FSPI);
static bool     s_uwbOk = false;
static bool     s_magOk = false;

static volatile bool s_irq = false;
static void IRAM_ATTR dwIsr() { s_irq = true; }

static constexpr uint8_t MMC_XOUT0 = 0x00;
static constexpr uint8_t MMC_ODR = 0x1A;
static constexpr uint8_t MMC_CTRL0  = 0x1B;
static constexpr uint8_t MMC_CTRL1  = 0x1C;
static constexpr uint8_t MMC_CTRL2 = 0x1D;
static constexpr uint8_t MMC_PRODUCT_ID = 0x39; 
static constexpr float   MAG_LSB = 0.0625f / 1000.0f;

static void dwHardReset() {
    pinMode(PIN_DW_RST, OUTPUT);
    digitalWrite(PIN_DW_RST, LOW);
    delay(2);
    pinMode(PIN_DW_RST, INPUT);  
    delay(5);
}

static uint16_t dwHeader(uint8_t file, uint16_t offset, bool write) {
    uint16_t h = (uint16_t)((file & 0x1F) << 9) | (uint16_t)((offset & 0x7F) << 2);
    if (write) h |= 0x8000;
    return h;
}

static uint32_t dwReadReg32(uint8_t file, uint16_t offset) {
    uint16_t hdr = dwHeader(file, offset, false);
    uint8_t  b[4] = {0, 0, 0, 0};

    dwSpi.beginTransaction(SPISettings(2000000, MSBFIRST, SPI_MODE0));
    digitalWrite(PIN_DW_CS, LOW);
    dwSpi.transfer((uint8_t)(hdr >> 8));
    dwSpi.transfer((uint8_t)(hdr & 0xFF));
    for (int i = 0; i < 4; i++) b[i] = dwSpi.transfer(0x00);
    digitalWrite(PIN_DW_CS, HIGH);
    dwSpi.endTransaction();

    return (uint32_t)b[3] << 24 | (uint32_t)b[2] << 16 | (uint32_t)b[1] << 8  | (uint32_t)b[0];
}

static bool uwbBegin() {
    pinMode(PIN_DW_CS, OUTPUT);
    digitalWrite(PIN_DW_CS, HIGH);
    pinMode(PIN_DW_WAKEUP, OUTPUT);
    digitalWrite(PIN_DW_WAKEUP, LOW);
    pinMode(PIN_DW_IRQ, INPUT);
    attachInterrupt(digitalPinToInterrupt(PIN_DW_IRQ), dwIsr, RISING);

    dwSpi.begin(PIN_DW_CLK, PIN_DW_MISO, PIN_DW_MOSI, PIN_DW_CS);
    dwHardReset();

    uint32_t devid = dwReadReg32(0x00, 0x00);
    Serial.printf("S,uwb devid=0x%08X\n", (unsigned int)devid);

    return (devid & 0xFFFF0000u) == 0xDECA0000u;
}

static void magWrite(uint8_t reg, uint8_t val) {
    Wire.beginTransmission(MMC5603_ADDR);
    Wire.write(reg);
    Wire.write(val);
    Wire.endTransmission();
}

static bool magRead(uint8_t reg, uint8_t* buf, size_t len) {
    Wire.beginTransmission(MMC5603_ADDR);
    Wire.write(reg);
    if (Wire.endTransmission(false) != 0) return false;
    if (Wire.requestFrom((int)MMC5603_ADDR, (int)len) != (int)len) return false;
    for (size_t i = 0; i < len; i++) buf[i] = Wire.read();
    return true;
}

static bool magBegin() {
    Wire.begin(PIN_MAG_SDA, PIN_MAG_SCL, 400000);

    uint8_t id = 0;
    if (!magRead(MMC_PRODUCT_ID, &id, 1) || id != 0x10) return false;

    magWrite(MMC_CTRL1, 0x80);
    delay(20);
    magWrite(MMC_ODR,   100); 
    magWrite(MMC_CTRL0, 0x80); 
    magWrite(MMC_CTRL2, 0x10); 
    magWrite(MMC_CTRL0, 0x20); 
    return true;
}

static bool magSample(float& mx, float& my, float& mz) {
    uint8_t b[6];
    if (!magRead(MMC_XOUT0, b, sizeof(b))) return false;

    auto be16 = [](const uint8_t* p) -> int32_t {
        return (int32_t)((uint32_t)p[0] << 8 | p[1]) - 32768;
    };
    mx = be16(&b[0]) * MAG_LSB;
    my = be16(&b[2]) * MAG_LSB;
    mz = be16(&b[4]) * MAG_LSB;
    return true;
}

void setup() {
    Serial.begin(LINK_BAUD, SERIAL_8N1, PIN_LINK_RX, PIN_LINK_TX);
    delay(50);
    Serial.println("S,esp32-c3 boot");

    s_uwbOk = uwbBegin();
    s_magOk = magBegin();

    Serial.printf("S,uwb=%d mag=%d\n", (int)s_uwbOk, (int)s_magOk);
}

void loop() {
    static char    rxbuf[64];
    static uint8_t rxlen = 0;
    while (Serial.available()) {
        char c = (char)Serial.read();
        if (c == '\n' || c == '\r') {
            if (rxlen) {
                rxbuf[rxlen] = '\0';
                if (rxbuf[0] == 'R') {
                    s_uwbOk = uwbBegin();
                    Serial.printf("S,uwb reset -> %d\n", (int)s_uwbOk);
                } else if (rxbuf[0] == '?') {
                    Serial.printf("S,uwb=%d mag=%d heap=%u\n",
                                  (int)s_uwbOk, (int)s_magOk,
                                  (unsigned)ESP.getFreeHeap());
                }
                rxlen = 0;
            }
        } else if (rxlen < sizeof(rxbuf) - 1) {
            rxbuf[rxlen++] = c;
        }
    }

    if (s_irq) {
        s_irq = false;
    }

    static uint32_t tMag = 0;
    if (s_magOk && millis() - tMag >= 20) {
        tMag = millis();
        float mx, my, mz;
        if (magSample(mx, my, mz)) {
            Serial.printf("M,%.4f,%.4f,%.4f\n", mx, my, mz);
        }
    }

    static uint32_t tPos = 0;
    if (s_uwbOk && millis() - tPos >= 100) {
        tPos = millis();
    }
}

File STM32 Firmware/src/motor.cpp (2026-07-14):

#include "motor.h"
#include "pins.h"
#include <math.h>

static HardwareTimer* s_tim  = nullptr;
static uint32_t s_period = 0; 
static bool s_enabled = false;
static float s_angle  = 0.0f;

void Motor::begin() {
    pinMode(PIN_M_NSLEEP, OUTPUT);
    digitalWrite(PIN_M_NSLEEP, LOW); 
    s_enabled = false;

    pinMode(PIN_M_NFAULT, INPUT_PULLUP); 

    pinMode(PIN_M_SOA, INPUT_ANALOG);
    pinMode(PIN_M_SOB, INPUT_ANALOG);
    pinMode(PIN_M_SOC, INPUT_ANALOG);

    s_tim = new HardwareTimer(TIM8);

    s_tim->setMode(1, TIMER_OUTPUT_COMPARE_PWM1, PIN_M_INHA);
    s_tim->setMode(1, TIMER_OUTPUT_COMPARE_PWM1, PIN_M_INLA);
    s_tim->setMode(2, TIMER_OUTPUT_COMPARE_PWM1, PIN_M_INHB);
    s_tim->setMode(2, TIMER_OUTPUT_COMPARE_PWM1, PIN_M_INLB);
    s_tim->setMode(3, TIMER_OUTPUT_COMPARE_PWM1, PIN_M_INHC);
    s_tim->setMode(3, TIMER_OUTPUT_COMPARE_PWM1, PIN_M_INLC);

    s_tim->setOverflow(PWM_FREQ_HZ * 2, HERTZ_FORMAT);
    s_period = s_tim->getOverflow(TICK_FORMAT);

    TIM_HandleTypeDef* h = s_tim->getHandle();

    h->Instance->CR1 &= ~TIM_CR1_CMS;
    h->Instance->CR1 |= TIM_CR1_CMS_0;

    TIM_BreakDeadTimeConfigTypeDef bdt = {};
    bdt.OffStateRunMode  = TIM_OSSR_ENABLE;
    bdt.OffStateIDLEMode = TIM_OSSI_ENABLE;
    bdt.LockLevel = TIM_LOCKLEVEL_OFF;
    bdt.DeadTime = DEADTIME_TICKS;
    bdt.BreakState = TIM_BREAK_DISABLE;
    bdt.BreakPolarity = TIM_BREAKPOLARITY_HIGH;
    bdt.BreakFilter = 0;
    bdt.Break2State = TIM_BREAK2_DISABLE;
    bdt.AutomaticOutput = TIM_AUTOMATICOUTPUT_DISABLE;
    HAL_TIMEx_ConfigBreakDeadTime(h, &bdt);

    coast();
    s_tim->resume();
}

void Motor::enable() {
    coast();          
    digitalWrite(PIN_M_NSLEEP, HIGH);
    delay(2);          
    s_enabled = true;
}

void Motor::disable() {
    coast();
    digitalWrite(PIN_M_NSLEEP, LOW);
    s_enabled = false;
}

bool Motor::enabled()  { return s_enabled; }
bool Motor::faulted()  { return digitalRead(PIN_M_NFAULT) == LOW; }

void Motor::clearFault() {
    digitalWrite(PIN_M_NSLEEP, LOW);
    delay(2);                           
    digitalWrite(PIN_M_NSLEEP, HIGH);
    delay(2);
}

void Motor::setPhaseDuty(float a, float b, float c) {
    if (!s_enabled) { a = b = c = 0.0f; }
    a = constrain(a, 0.0f, 0.98f);
    b = constrain(b, 0.0f, 0.98f);       
    c = constrain(c, 0.0f, 0.98f);

    s_tim->setCaptureCompare(1, (uint32_t)(a * s_period), TICK_COMPARE_FORMAT);
    s_tim->setCaptureCompare(2, (uint32_t)(b * s_period), TICK_COMPARE_FORMAT);
    s_tim->setCaptureCompare(3, (uint32_t)(c * s_period), TICK_COMPARE_FORMAT);
}

void Motor::coast() {
    s_tim->setCaptureCompare(1, 0u, TICK_COMPARE_FORMAT);
    s_tim->setCaptureCompare(2, 0u, TICK_COMPARE_FORMAT);
    s_tim->setCaptureCompare(3, 0u, TICK_COMPARE_FORMAT);
}

void Motor::brake() {
    coast();
}

void Motor::setSVPWM(float angle_rad, float amplitude) {
    amplitude = constrain(amplitude, 0.0f, 1.0f);

    const float k = 2.0f * PI / 3.0f;
    float a = sinf(angle_rad);
    float b = sinf(angle_rad - k);
    float c = sinf(angle_rad + k);

    float vmax = fmaxf(a, fmaxf(b, c));
    float vmin = fminf(a, fminf(b, c));
    float com  = (vmax + vmin) * 0.5f;

    a = (a - com) * amplitude * 0.5f + 0.5f;
    b = (b - com) * amplitude * 0.5f + 0.5f;
    c = (c - com) * amplitude * 0.5f + 0.5f;

    setPhaseDuty(a, b, c);
}

void Motor::openLoopSpin(float elec_hz, float amplitude, float dt_s) {
    s_angle += 2.0f * PI * elec_hz * dt_s;
    while (s_angle > 2.0f * PI) s_angle -= 2.0f * PI;
    while (s_angle < 0.0f)      s_angle += 2.0f * PI;
    setSVPWM(s_angle, amplitude);
}

Motor::Currents Motor::readCurrents() {
    Currents c;
    c.a = analogRead(PIN_M_SOA) / 4095.0f * ADC_VREF;
    c.b = analogRead(PIN_M_SOB) / 4095.0f * ADC_VREF;
    c.c = analogRead(PIN_M_SOC) / 4095.0f * ADC_VREF;
    return c;
}
